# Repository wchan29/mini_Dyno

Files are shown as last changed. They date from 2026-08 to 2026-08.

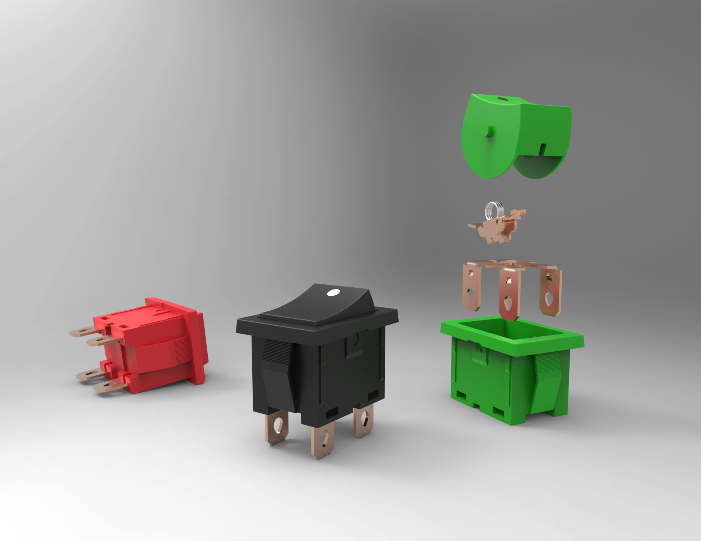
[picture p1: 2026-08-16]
Dyno Enclosure REV_B/220 - Electronics/220 - Electronics Encapsulation/OnOff Switch/on-off-switch-4.snapshot.2/Renderings/On off switch.1.jpg

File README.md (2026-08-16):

# Mini Dyno

Mechanical design files for a compact 10 N·m dynamometer built for the [WEMPEC](https://wempec.wisc.edu/) research lab at UW-Madison.

## Overview

A dynamometer measures the rotational speed and torque output of a motor to determine instantaneous power and efficiency. This project is a bench-scale dynamometer for characterizing small electric machines (up to IEC100 frame size), designed to:

- Fit on a standard lab bench
- House a pre-selected Rockwell Kinetix MP servo as the load motor
- Enclose the test setup for operator protection
- Allow quick installation/removal of test motors with minimal realignment
- Support HMI control from the enclosure door

More background and photos: https://wchan29.github.io/portfolio/wempec_mini_dyne/

## Design

**Mechanical**
- ThorLabs MB3090/M aluminum optical breadboard as the baseplate
- MISUMI L-shaped welded mounts for servo motor attachment
- OptoSigma optical rails and carriages for interchangeable test-motor mounting
- 8020 T-slot aluminum framing for the enclosure
- 1/4" polycarbonate protective panels

**Electrical**
- Servo drive: Allen-Bradley Kinetix 300 (2097-V33PR6, 3 kW)
- Load motor: Rockwell Kinetix MPL-A4540F-MJ74AA (2.6 kW, 3000 RPM)
- HMI: 7" Rockwell PanelView 800 touchscreen mounted on the enclosure door
- Controller: Micro820 PLC over Ethernet
- Supporting hardware: 24V DC power supply, Ethernet hub, brake relay, torque transducer module

**Specs**
- Max torque: 10 N·m
- Max speed: 3000 RPM

The servo and torque transducer are mounted as a swappable unit on the optical rail carriage, so either can be serviced or replaced independently of the rest of the setup.

## Repository contents

All design files live under [`Dyno Enclosure REV_B/`](Dyno%20Enclosure%20REV_B/), a SolidWorks project:

| Folder / File | Contents |
| --- | --- |
| `220 - Dyno Enclosure - 8020/` | T-slot frame, door, and hinge assemblies |
| `220 - Dyno Enclosure - Optical Table/` | Optical breadboard baseplate |
| `220 - Dyno Enclosure - OptoSigma/` | Optical rail and carriage components |
| `220 - Dyno Enclosure - Polycarbonate/` | Enclosure panels |
| `220 - Optical Rail and Carriage/` | Motor mounting carriage hardware |
| `220 - Bracket & Misc/` | Brackets, alignment jig, torque transducer base, couplings |
| `220 - Cable Routing/` | Cable management components |
| `220 - Electronics/` | Electrical/control hardware models |
| `Pictures/` | Reference images |
| `220 - Dyno Enclosure - BOM.SLDDRW` / `..._BOM_PDF.pdf` | Bill of materials |
| `_220 - Dyno Enclosure - Enclosure Full Assembly.SLDASM` | Top-level enclosure assembly |
| `220 - Dyno Setup Assembly.SLDASM` | Top-level full dyno assembly |

Files are native SolidWorks (`.SLDPRT`/`.SLDASM`/`.SLDDRW`), with some parts also provided as `.igs`/`.DXF`/`.pdf` for interchange. Requires SolidWorks (or a compatible viewer) to open.

## License

This work is licensed under [CC BY 4.0](LICENSE).

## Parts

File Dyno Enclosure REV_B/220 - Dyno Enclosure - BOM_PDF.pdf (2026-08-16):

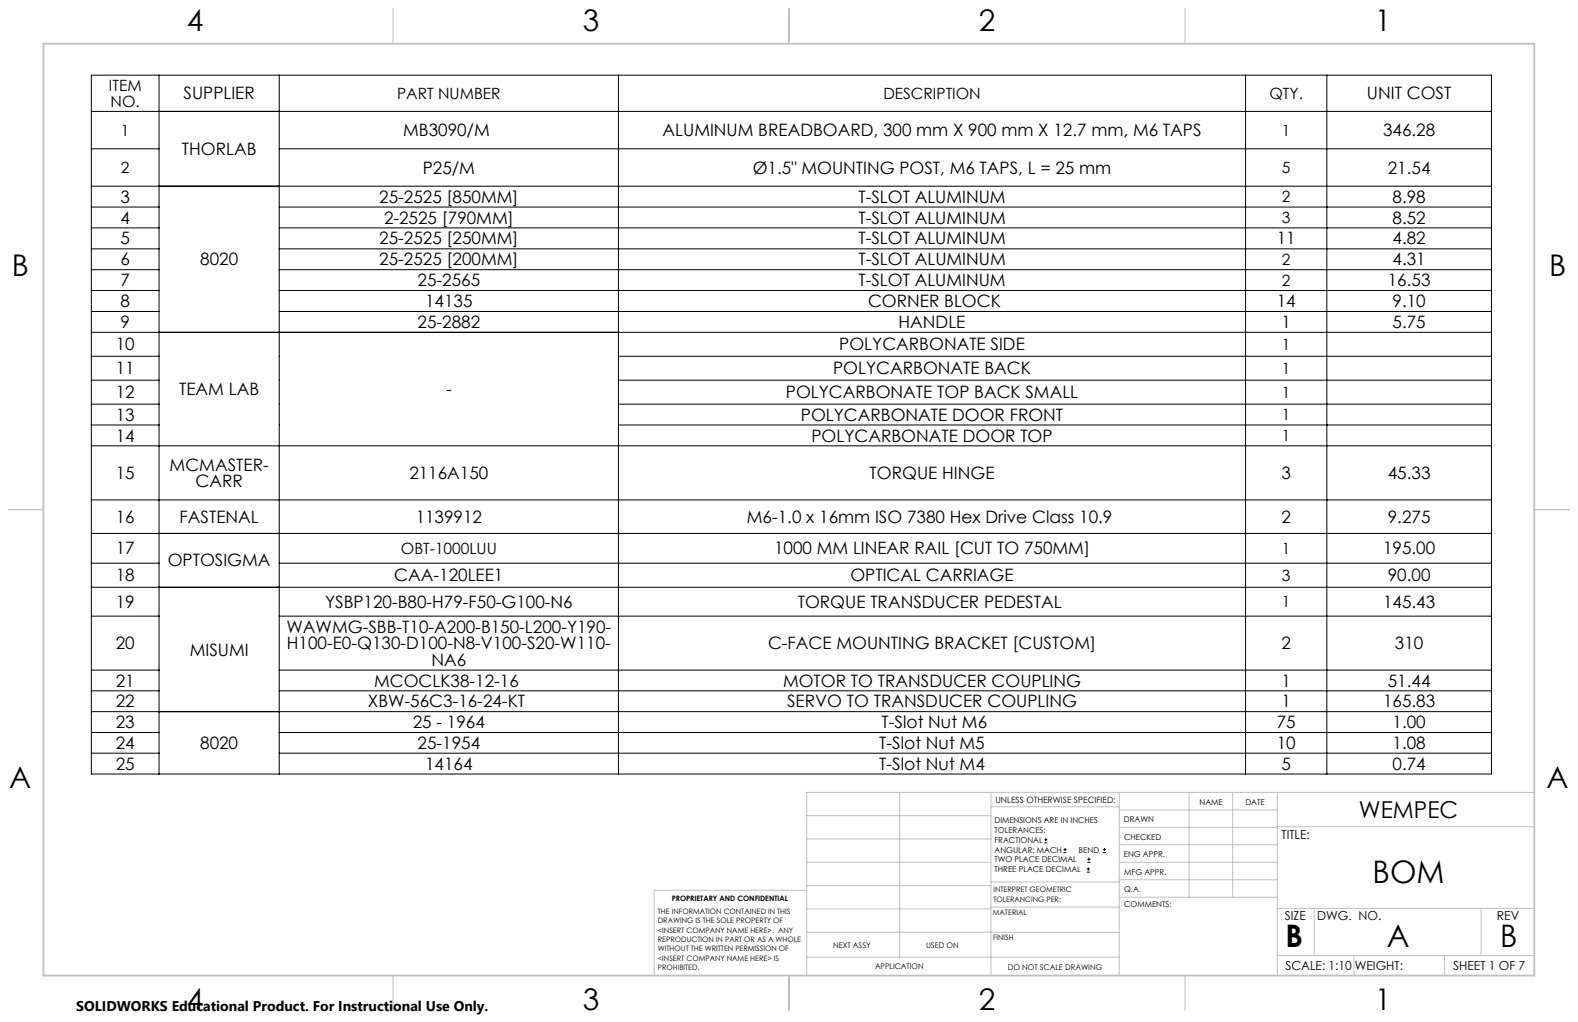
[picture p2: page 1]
SUPPLIER; PART NUMBER; DESCRIPTION; QTY.; UNIT COST; ALUMINUM BREADBOARD, 300 mm X 900 mm X 12.7 mm, M6 TAPS; Ø1.5" MOUNTING POST, M6 TAPS, L = 25 mm; T-SLOT ALUMINUM; CORNER BLOCK; TEAM LAB; POLYCARBONATE SIDE; POLYCARBONATE BACK; POLYCARBONATE TOP BACK SMALL; POLYCARBONATE DOOR FRONT; POLYCARBONATE DOOR TOP; CARR; TORQUE HINGE; FASTENAL; M6-1.0 x 16mm ISO 7380 Hex Drive Class 10.9; OPTOSIGMA; OBT-1000LUU; 1000 MM LINEAR RAIL [CUT TO 750MM]; CAA-120LEE1; OPTICAL CARRIAGE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

UNLESS OTHERWISE SPECIFIED: | | DATE | WEMPEC NAME
DIMENSIONS ARE IN INCHES TOLERANCES: FRACTIONAL ANGULAR: MACH BEND TWO PLACE DECIMAL THREE PLACE DECIMAL | DRAWN

CHECKED | | TITLE: BOM

ENG APPR.
MFG APPR.

INTERPRET GEOMETRIC TOLERANCING PER: | Q.A.
MATERIAL | | SIZE B | DWG. NO. A | REV B

PROPRIETARY AND CONFIDENTIAL
THE INFORMATION CONTAINED IN THIS
DRAWING IS THE SOLE PROPERTY OF
<INSERT COMPANY NAME HERE>. ANY
REPRODUCTION IN PART OR AS A WHOLE
WITHOUT THE WRITTEN PERMISSION OF
<INSERT COMPANY NAME HERE> IS
PROHIBITED.

NEXT ASSY | USED ON | FINISH

APPLICATION | DO NOT SCALE DRAWING | | SCALE: 1:10 WEIGHT: | | SHEET 1 OF 7

SOLIDWORKS Educational Product. For Instructional Use Only.

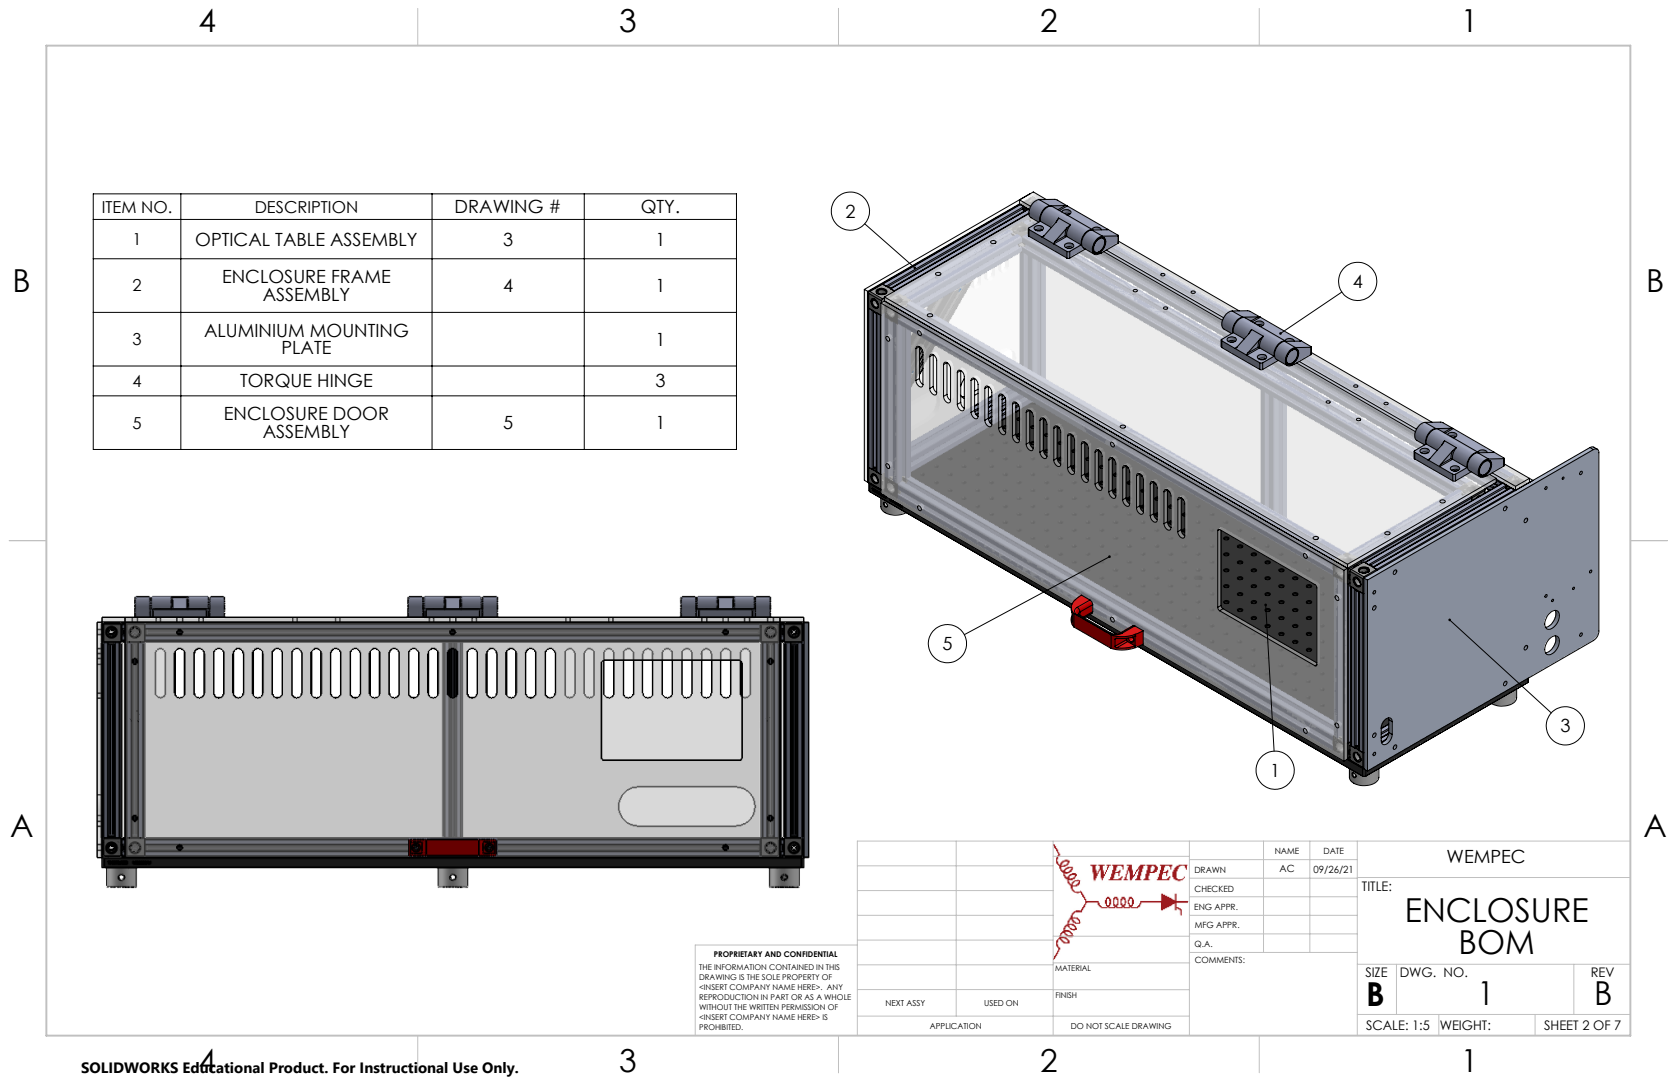
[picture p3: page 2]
SCALE: 1:5; WEIGHT:; DWG. NO.; REV

ITEM NO. | DESCRIPTION | DRAWING # | QTY.
1 | OPTICAL TABLE ASSEMBLY | 3 | 1
2 | ENCLOSURE FRAME ASSEMBLY | 4 | 1

3 | ALUMINIUM MOUNTING PLATE | | 1

4 | TORQUE HINGE | | 3
5 | ENCLOSURE DOOR ASSEMBLY | 5 | 1

NAME | DATE | WEMPEC
CHECKED | | | TITLE: ENCLOSURE BOM

DRAWN | AC | 09/26/21

ENG APPR.
MFG APPR.
Q.A.

PROPRIETARY AND CONFIDENTIAL
THE INFORMATION CONTAINED IN THIS
DRAWING IS THE SOLE PROPERTY OF
<INSERT COMPANY NAME HERE>. ANY

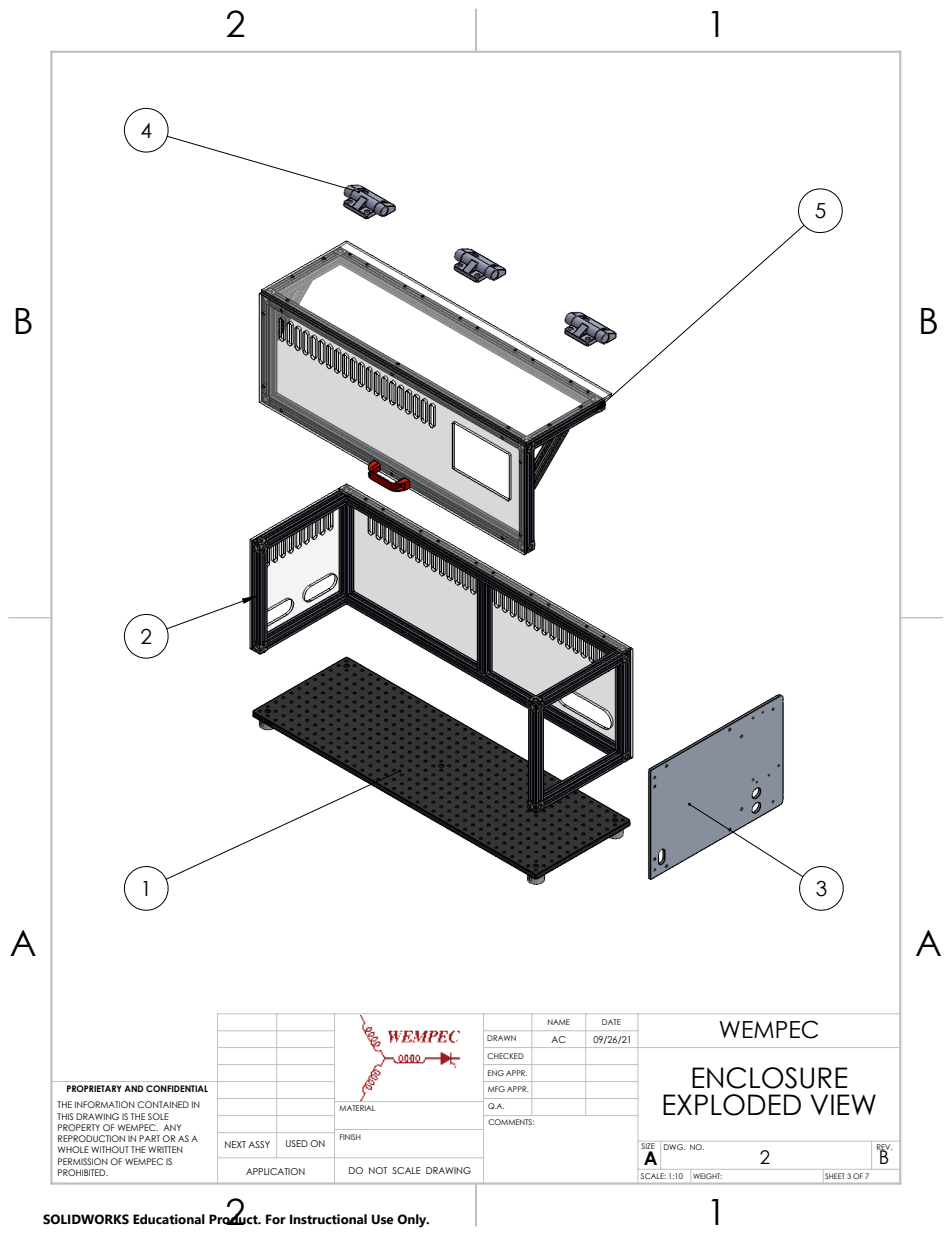
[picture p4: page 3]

AC NAME | 09/26/21 DATE | WEMPEC EXPLODED VIEW PROPRIETARY AND CONFIDENTIAL

DRAWN
CHECKED | | | ENCLOSURE
ENG APPR.

THE INFORMATION CONTAINED IN THIS DRAWING IS THE SOLE PROPERTY OF WEMPEC. ANY REPRODUCTION IN PART OR AS A WHOLE WITHOUT THE WRITTEN PERMISSION OF WEMPEC IS | | MFG APPR.

MATERIAL | Q.A.

SIZE A | DWG. NO. 2 | REV. B

APPLICATION | DO NOT SCALE DRAWING

SCALE: 1:10 | WEIGHT:

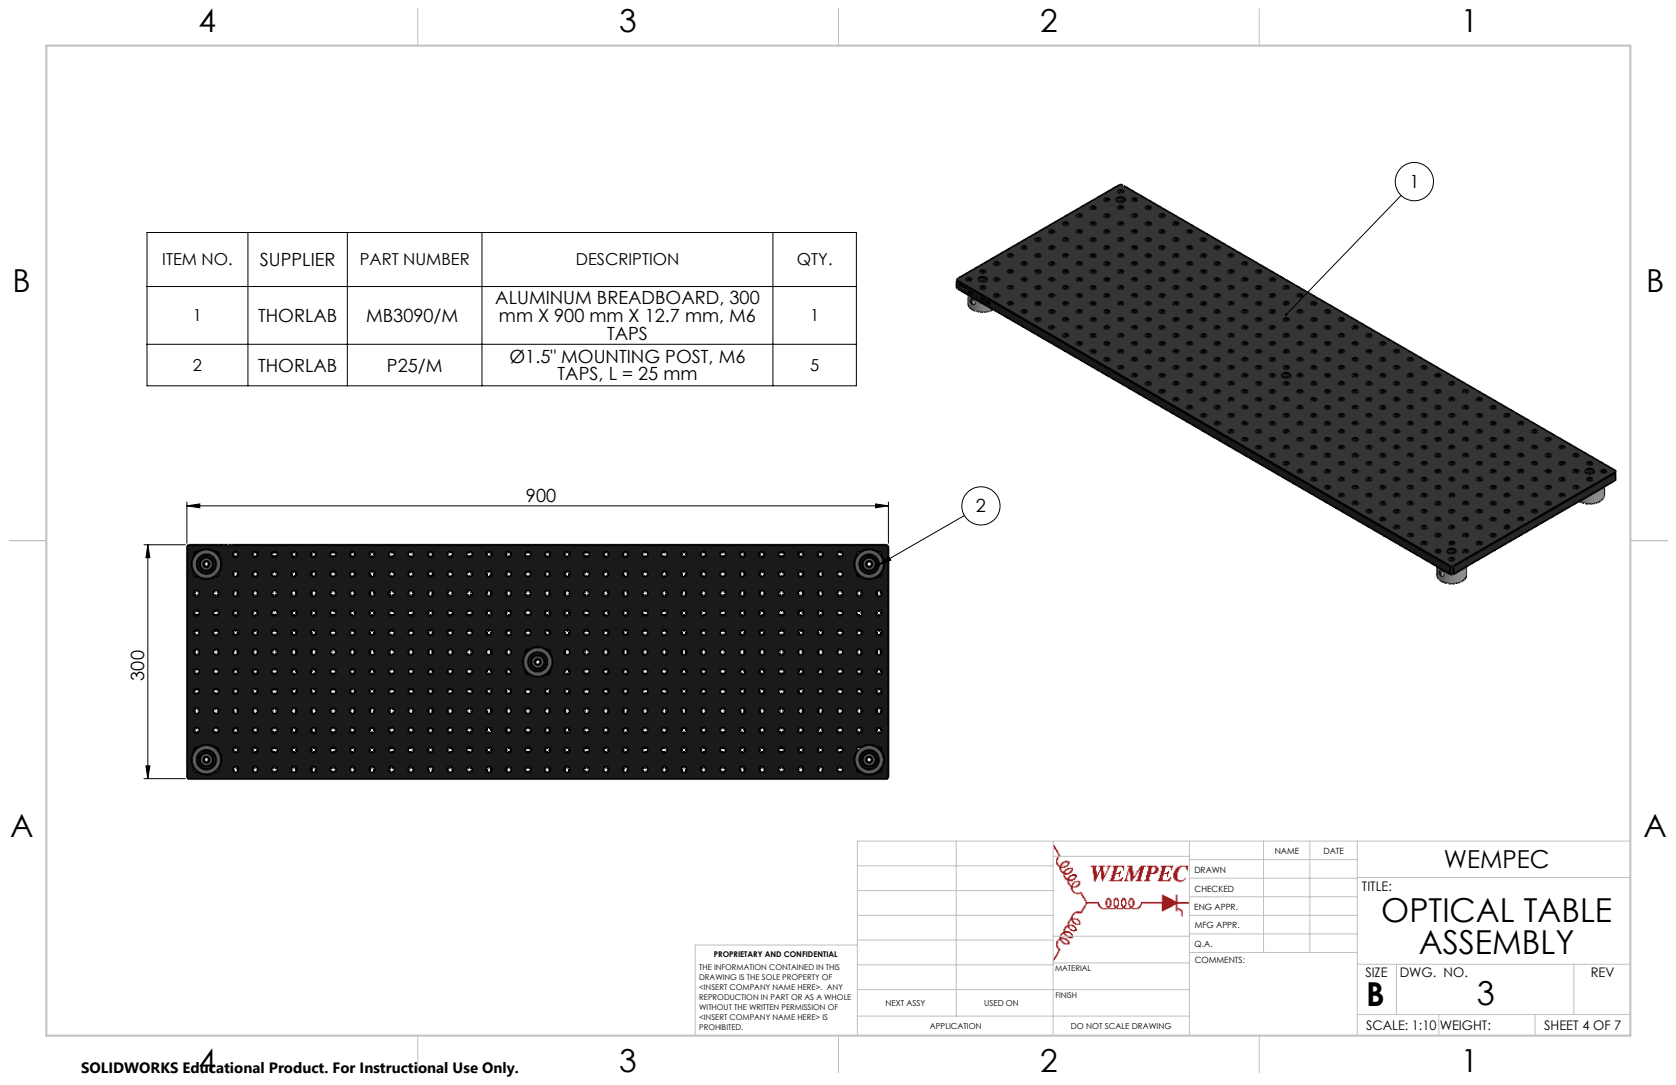
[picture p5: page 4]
SCALE: 1:10 WEIGHT:; SHEET 4 OF 7; DWG. NO.; REV

ITEM NO. | SUPPLIER | PART NUMBER | DESCRIPTION | QTY.
1 | THORLAB | MB3090/M | ALUMINUM BREADBOARD, 300 mm X 900 mm X 12.7 mm, M6 TAPS | 1

2 | THORLAB | P25/M | Ø1.5" MOUNTING POST, M6 TAPS, L = 25 mm | 5

DATE | WEMPEC NAME
CHECKED | TITLE: OPTICAL TABLE ASSEMBLY

DRAWN

ENG APPR.
MFG APPR.
Q.A.

PROPRIETARY AND CONFIDENTIAL
THE INFORMATION CONTAINED IN THIS
DRAWING IS THE SOLE PROPERTY OF
<INSERT COMPANY NAME HERE>. ANY

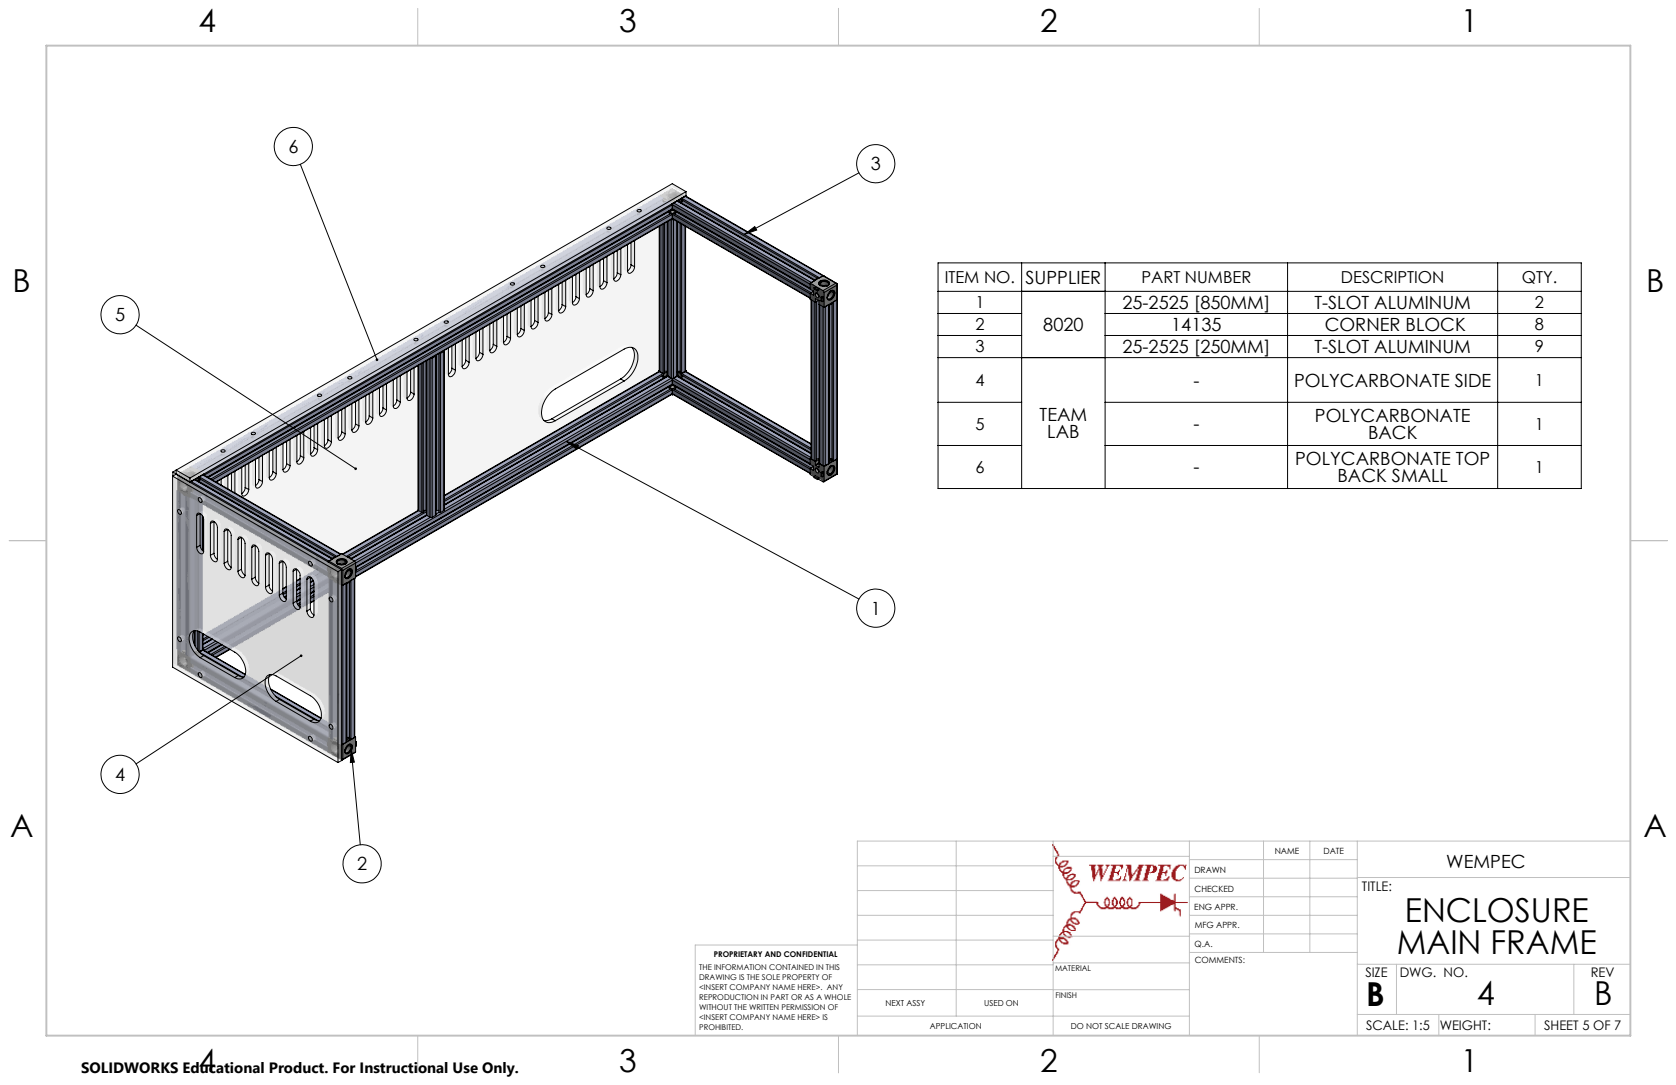
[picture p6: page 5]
SCALE: 1:5; WEIGHT:; SHEET 5 OF 7; DWG. NO.; REV

ITEM NO. | SUPPLIER | PART NUMBER | DESCRIPTION | QTY.
1 | 8020 | 25-2525 [850MM] | T-SLOT ALUMINUM | 2
2 | | 14135 | CORNER BLOCK | 8
3 | | 25-2525 [250MM] | T-SLOT ALUMINUM | 9
4 | TEAM LAB | - | POLYCARBONATE SIDE | 1
5 | | - | POLYCARBONATE BACK | 1
6 | | - | POLYCARBONATE TOP BACK SMALL | 1

NAME | DATE | WEMPEC
CHECKED | | | TITLE: ENCLOSURE MAIN FRAME

DRAWN

ENG APPR.
MFG APPR.
Q.A.

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

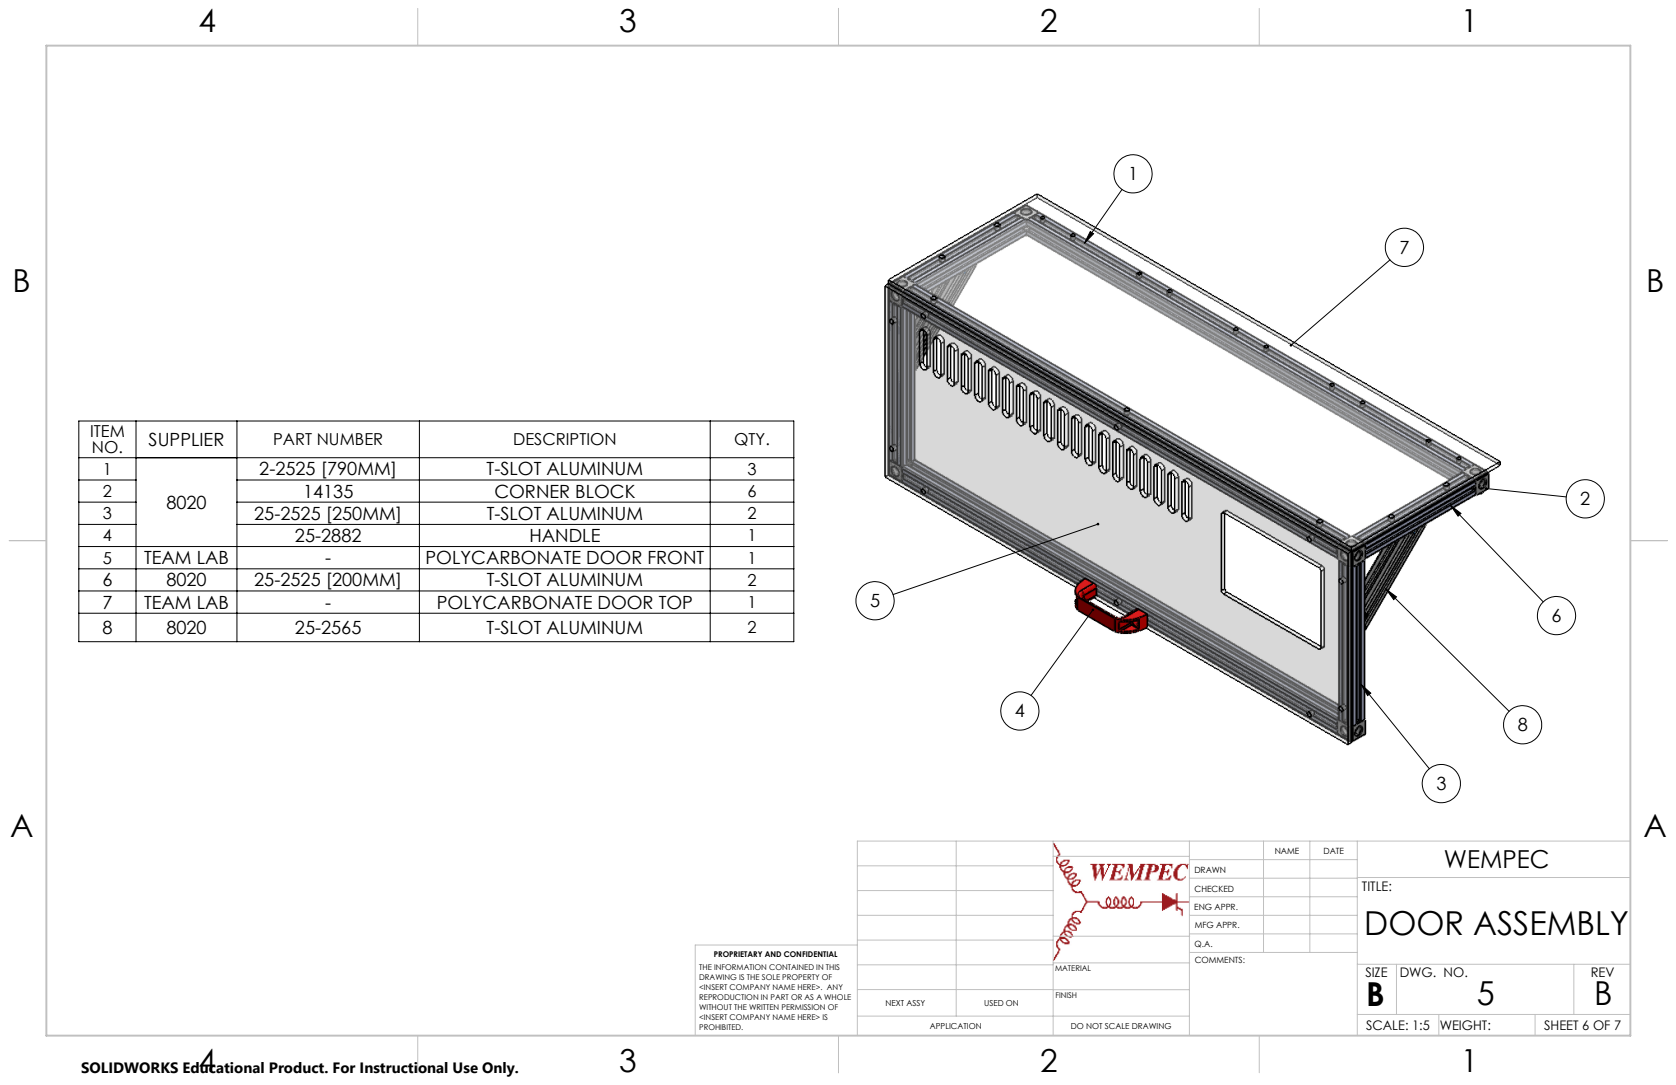
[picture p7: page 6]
SCALE: 1:5; WEIGHT:; SHEET 6 OF 7; DWG. NO.; REV

ITEM NO. | SUPPLIER | PART NUMBER | DESCRIPTION | QTY.
1 | 8020 | 2-2525 [790MM] | T-SLOT ALUMINUM | 3
2 | | 14135 | CORNER BLOCK | 6
3 | | 25-2525 [250MM] | T-SLOT ALUMINUM | 2
4 | | 25-2882 | HANDLE | 1
5 | TEAM LAB | - | POLYCARBONATE DOOR FRONT | 1
6 | 8020 | 25-2525 [200MM] | T-SLOT ALUMINUM | 2
7 | TEAM LAB | - | POLYCARBONATE DOOR TOP | 1
8 | 8020 | 25-2565 | T-SLOT ALUMINUM | 2

DATE | WEMPEC NAME
CHECKED | TITLE: DOOR ASSEMBLY

DRAWN

ENG APPR.
MFG APPR.
Q.A.

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

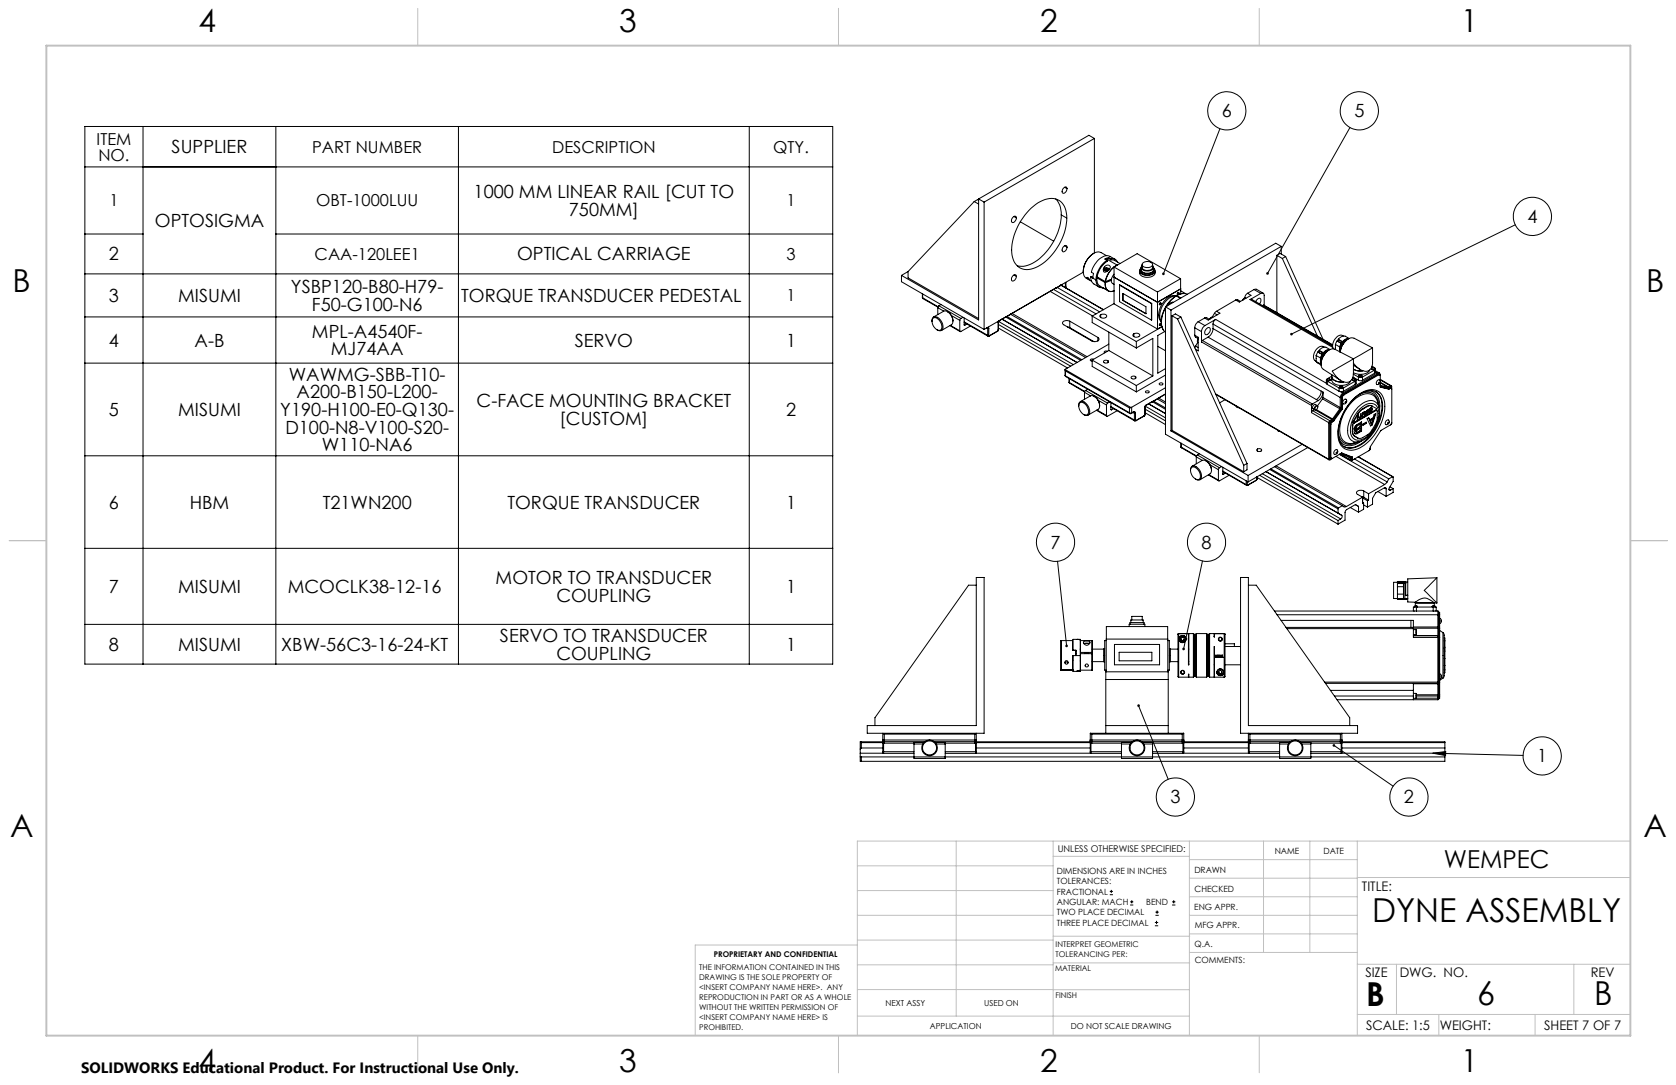
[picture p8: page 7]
SCALE: 1:5; WEIGHT:; DWG. NO.; REV

ITEM NO. | SUPPLIER | PART NUMBER | DESCRIPTION | QTY.

1 | OPTOSIGMA | OBT-1000LUU | 1000 MM LINEAR RAIL [CUT TO 750MM] | 1

2 | | CAA-120LEE1 | OPTICAL CARRIAGE | 3
3 | MISUMI | YSBP120-B80-H79-F50-G100-N6 | TORQUE TRANSDUCER PEDESTAL | 1
4 | A-B | MPL-A4540F-MJ74AA | SERVO | 1
5 | MISUMI | WAWMG-SBB-T10-A200-B150-L200-Y190-H100-E0-Q130-D100-N8-V100-S20-W110-NA6 | C-FACE MOUNTING BRACKET [CUSTOM] | 2

6 | HBM | T21WN200 | TORQUE TRANSDUCER | 1

7 | MISUMI | MCOCLK38-12-16 | MOTOR TO TRANSDUCER COUPLING | 1

8 | MISUMI | XBW-56C3-16-24-KT | SERVO TO TRANSDUCER COUPLING | 1

UNLESS OTHERWISE SPECIFIED: | | DATE | WEMPEC NAME
DIMENSIONS ARE IN INCHES TOLERANCES: FRACTIONAL ANGULAR: MACH BEND TWO PLACE DECIMAL THREE PLACE DECIMAL | DRAWN

CHECKED | | TITLE: DYNE ASSEMBLY

ENG APPR.
MFG APPR.

INTERPRET GEOMETRIC TOLERANCING PER: | Q.A.

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

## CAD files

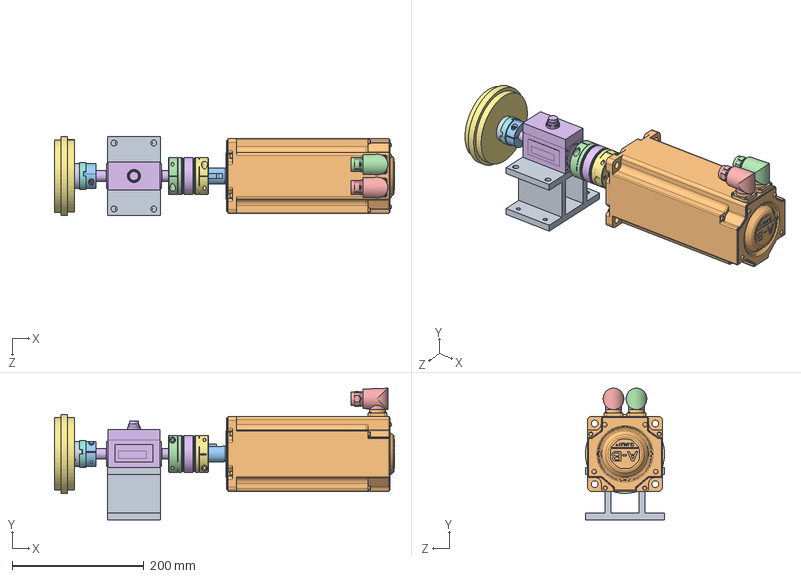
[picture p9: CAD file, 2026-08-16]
Dyno Enclosure REV_B/220 - Dyno Setup Assembly.SLDASM
515.2 x 199.6 x 120.0 mm
220 - Torque Transducer Base - YSBP120_B80_H79_F50_G100_N6
Rockwell Automation-MPL-x4540x-xJ74AA_MPL-45xx-Body
Rockwell Automation-MPL-x4540x-xJ74AA_MPL-45xx-Shaft
Rockwell Automation-MPL-x4540x-xJ74AA_MPL-3xx-Power Connector
Rockwell Automation-MPL-x4540x-xJ74AA_MPL-3xx-Encoder Connector
T21WN_20_0_SW
_MCOC_spacer38_2
_MCOCLK38_12_c_4
_M5_16_bo2_6 x 2
_MCOC38_16_c_8
_XBW-56C3 - 16-24 - Hub 1.stp
_XBW-56C3 - Disk.stp x 2
_XBW-56C3 - Spacer.stp
_XBW-56C3 - 16-24 - Hub 2.stp

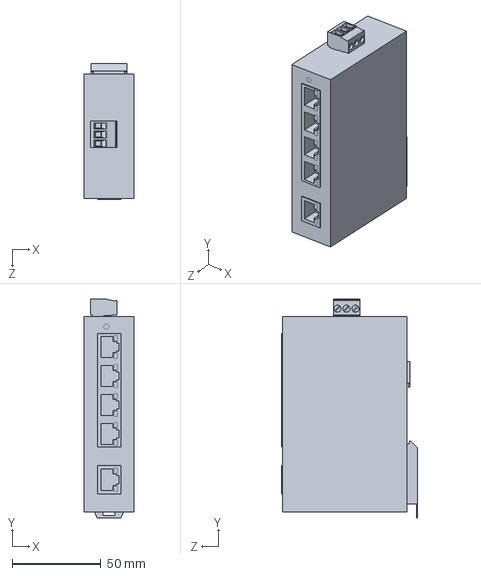
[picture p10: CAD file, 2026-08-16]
Dyno Enclosure REV_B/220 - Electronics/220 - PXC - FL-SWITCH-SFNB-5TX_3D/220 - PXC - FL-SWITCH-SFNB-5TX_3D.SLDASM
28.0 x 123.2 x 76.7 mm

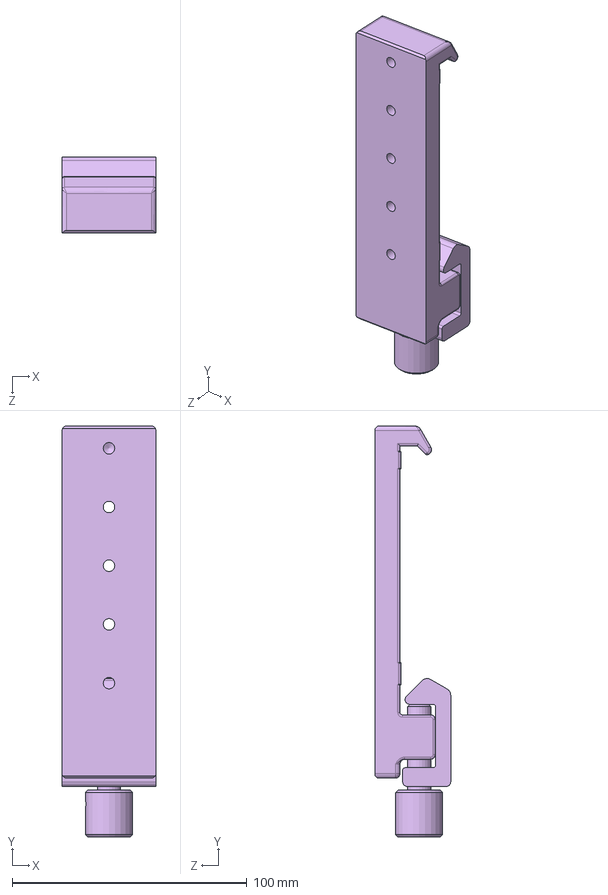
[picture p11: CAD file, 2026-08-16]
Dyno Enclosure REV_B/220 - Optical Rail and Carriage/CAA-40LEE.SLDASM
40.0 x 175.1 x 32.2 mm
CAA-40LEE1
CAA-40LEE2
CAA-40LEE3
CAA-40LEE4
CAA-40LEE5
CAA-40LEE6

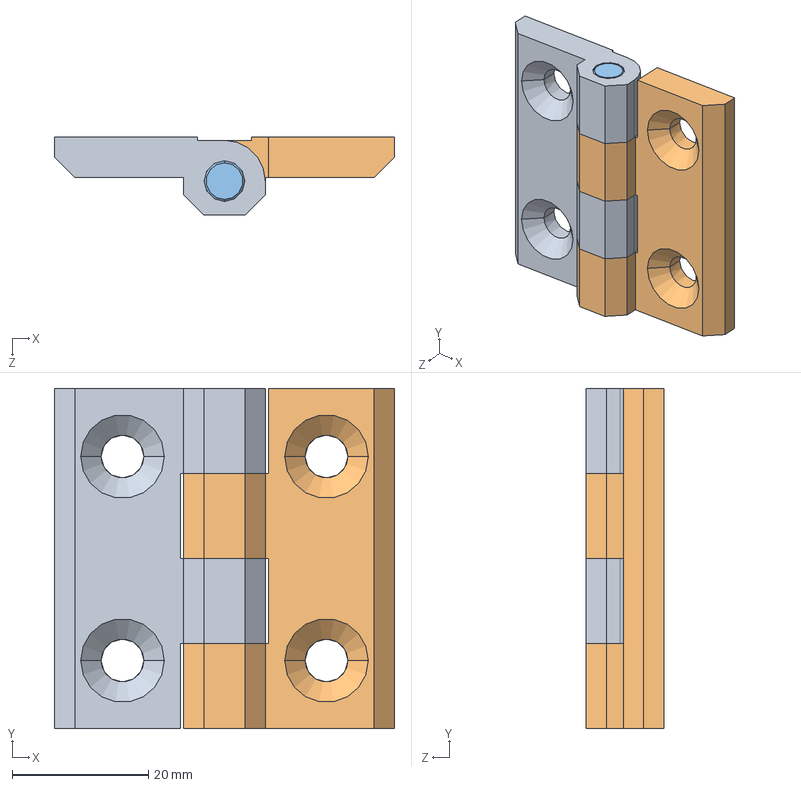
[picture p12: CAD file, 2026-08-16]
Dyno Enclosure REV_B/220 - Dyno Enclosure - 8020/220 - Hinge/220 - Dyno Enclosure - 8020 - Hinge - 12256.sldasm
50.0 x 50.0 x 11.5 mm
_12256_a_2
_12256_b_4
_12256_pin_6

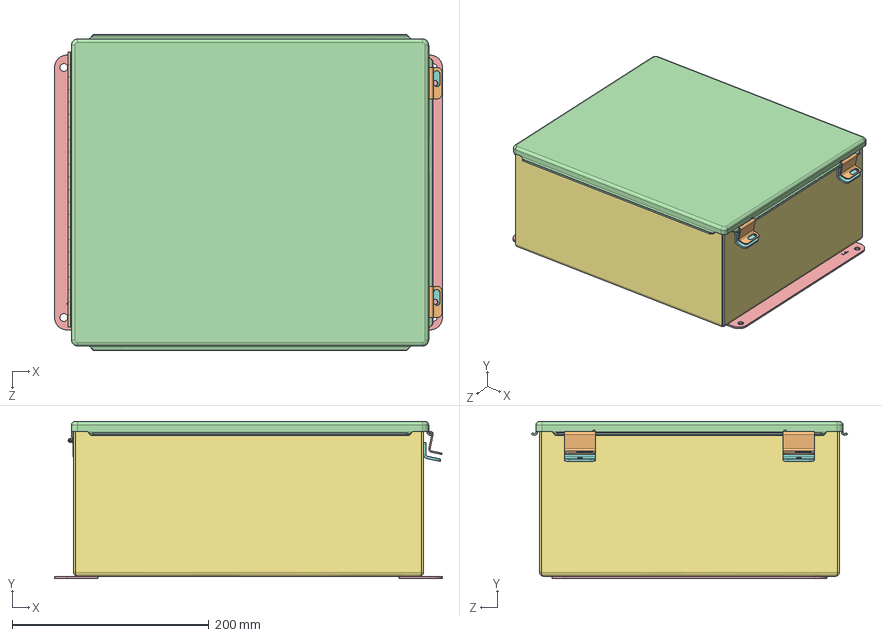
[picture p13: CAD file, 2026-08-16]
Dyno Enclosure REV_B/220 - Electronics/220 - Electronics Encapsulation/220 - Dyno Enclosure - Electronics Box.SLDASM
394.2 x 159.8 x 321.1 mm
89053215.stp
89053200.stp x 2
99404181.stp
58346025.stp
54208005_54208005.stp x 2
54106001.stp x 4
54321010.stp
54102001.stp x 2
54206007_PER MODEL.stp
54101001.stp x 2

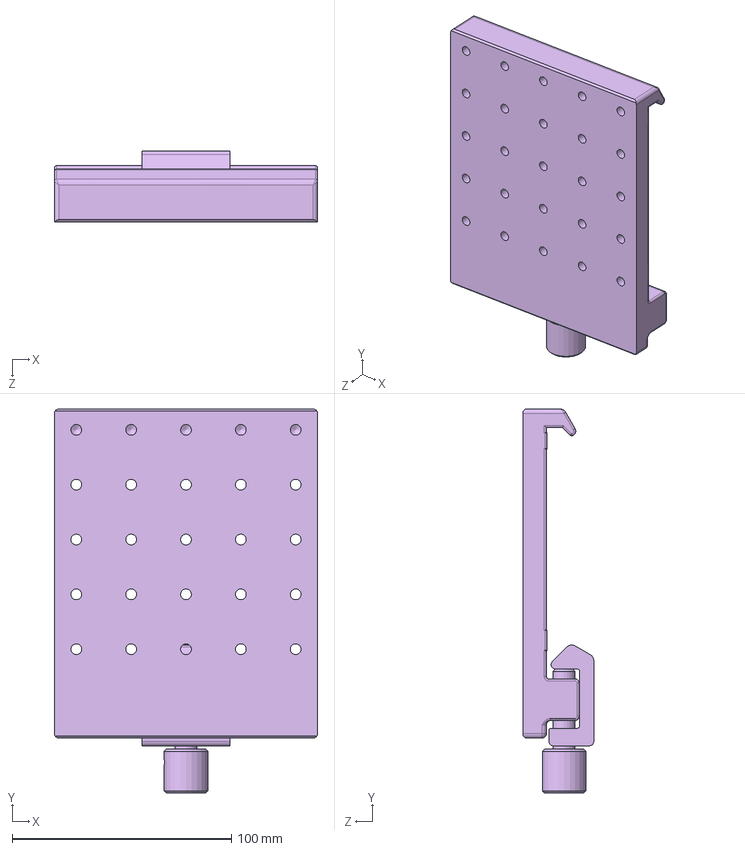
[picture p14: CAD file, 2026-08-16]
Dyno Enclosure REV_B/220 - Optical Rail and Carriage/CAA-120LEE.SLDASM
120.0 x 175.1 x 32.2 mm
CAA-120LEE1
CAA-120LEE2
CAA-120LEE3
CAA-120LEE4
CAA-120LEE5
CAA-120LEE6

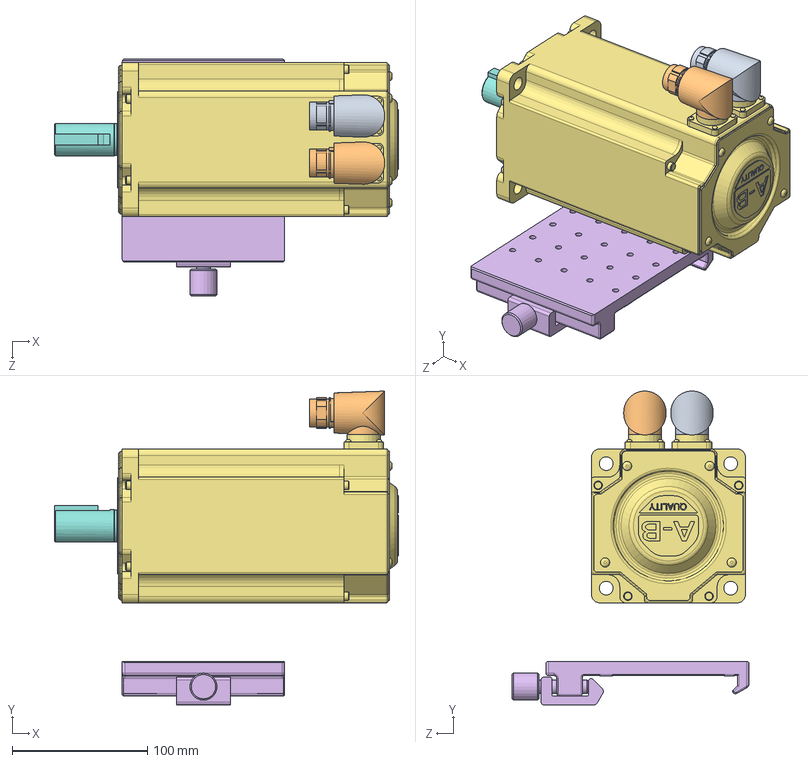
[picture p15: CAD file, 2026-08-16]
Dyno Enclosure REV_B/220 - Motor Carriage.SLDASM
254.0 x 231.8 x 175.1 mm
CAA-120LEE1
CAA-120LEE2
CAA-120LEE3
CAA-120LEE4
CAA-120LEE5
CAA-120LEE6
Rockwell Automation-MPL-x4540x-xJ74AA_MPL-45xx-Body
Rockwell Automation-MPL-x4540x-xJ74AA_MPL-45xx-Shaft
Rockwell Automation-MPL-x4540x-xJ74AA_MPL-3xx-Power Connector
Rockwell Automation-MPL-x4540x-xJ74AA_MPL-3xx-Encoder Connector

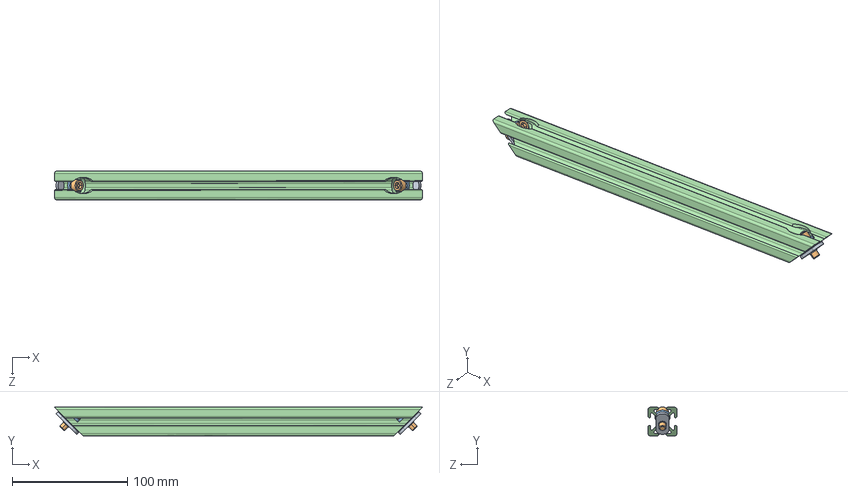
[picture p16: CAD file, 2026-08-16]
Dyno Enclosure REV_B/220 - Dyno Enclosure - 8020/8020_252570/SOLIDWORKS/25_2570.sldasm
320.0 x 25.2 x 25.0 mm

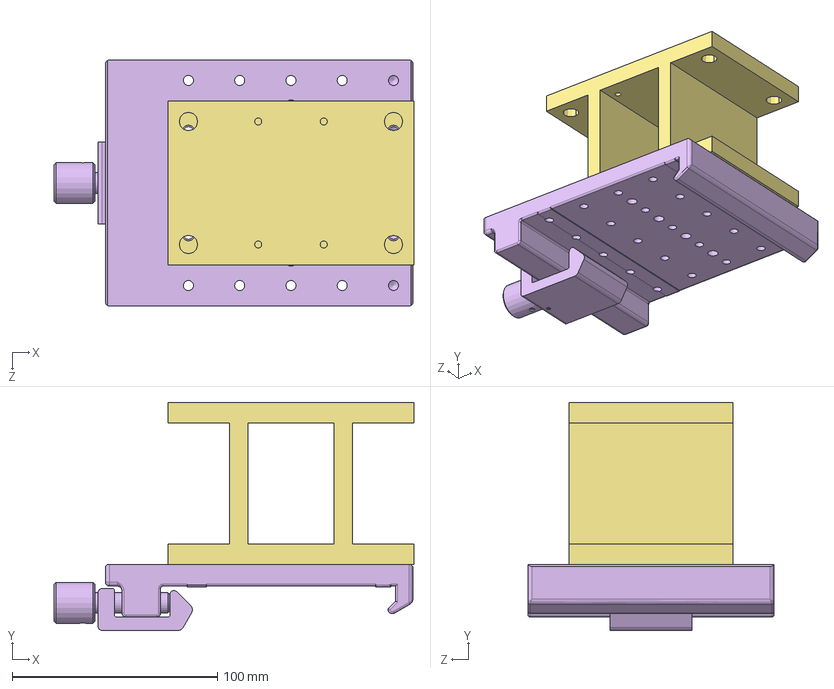
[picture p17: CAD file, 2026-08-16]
Dyno Enclosure REV_B/220 - Torque Transducer Carraige.SLDASM
175.5 x 111.2 x 120.0 mm
CAA-120LEE1
CAA-120LEE2
CAA-120LEE3
CAA-120LEE4
CAA-120LEE5
CAA-120LEE6
220 - Torque Transducer Base - YSBP120_B80_H79_F50_G100_N6

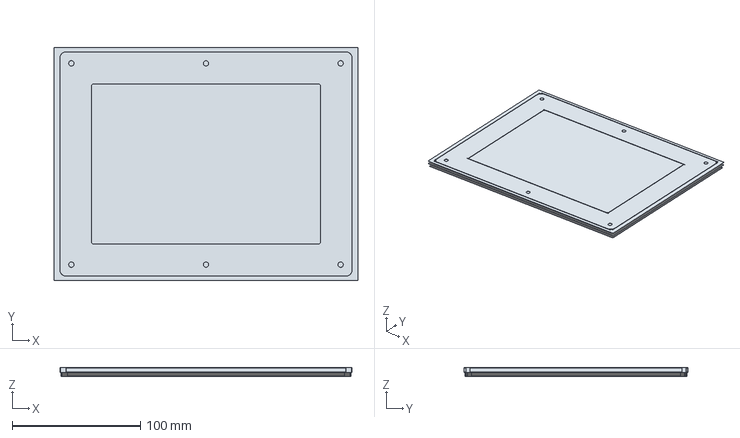
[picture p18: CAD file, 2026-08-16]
Dyno Enclosure REV_B/220 - Dyno Enclosure - Polycarbonate/2711R_APK7_Assy_3D.igs
237.1 x 182.0 x 7.04 mm

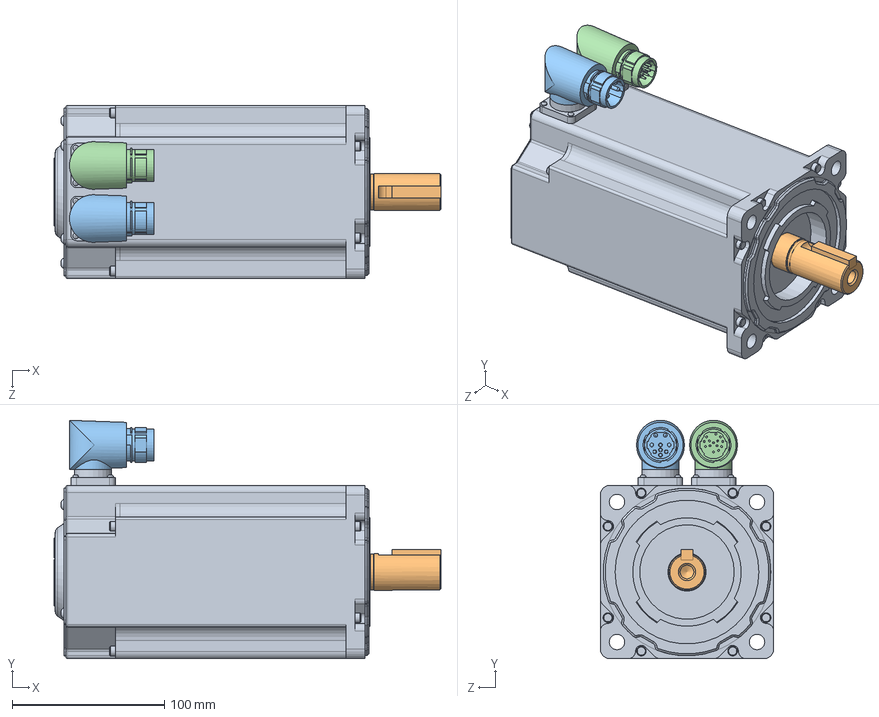
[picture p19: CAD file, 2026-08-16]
Dyno Enclosure REV_B/220 - Electronics/220 - Rockwell Automation-MPL-X4540X-XJ74AA Motor/Rockwell Automation-MPL-x4540x-xJ74AA.SLDASM
254.0 x 156.5 x 113.8 mm
Rockwell Automation-MPL-x4540x-xJ74AA_MPL-45xx-Body
Rockwell Automation-MPL-x4540x-xJ74AA_MPL-45xx-Shaft
Rockwell Automation-MPL-x4540x-xJ74AA_MPL-3xx-Power Connector
Rockwell Automation-MPL-x4540x-xJ74AA_MPL-3xx-Encoder Connector

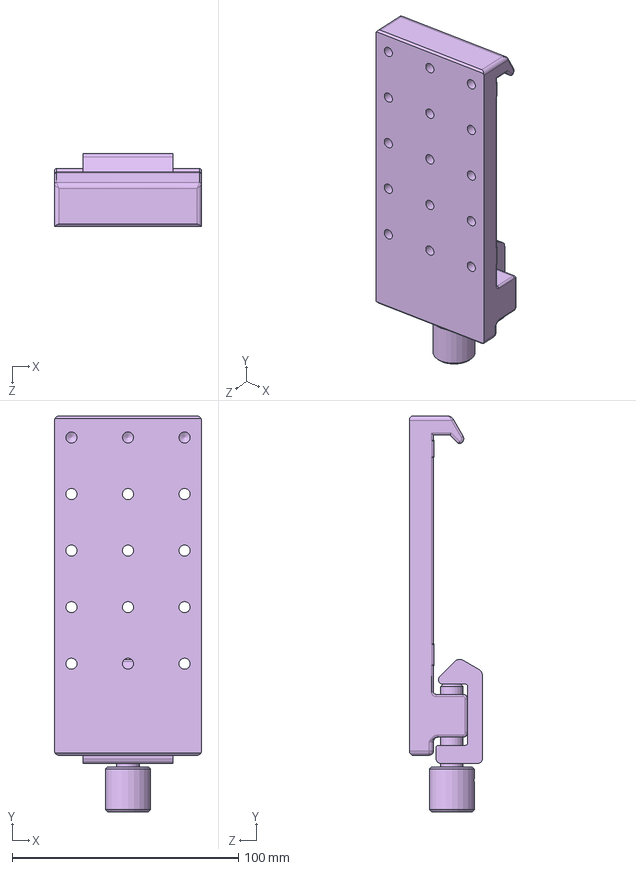
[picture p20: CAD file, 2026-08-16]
Dyno Enclosure REV_B/220 - Dyno Enclosure - OptoSigma/220 - Optical Carriage/CAA-65LEE.SLDASM
65.0 x 175.1 x 32.2 mm
CAA-65LEE1
CAA-65LEE2
CAA-65LEE3
CAA-65LEE4
CAA-65LEE5
CAA-65LEE6

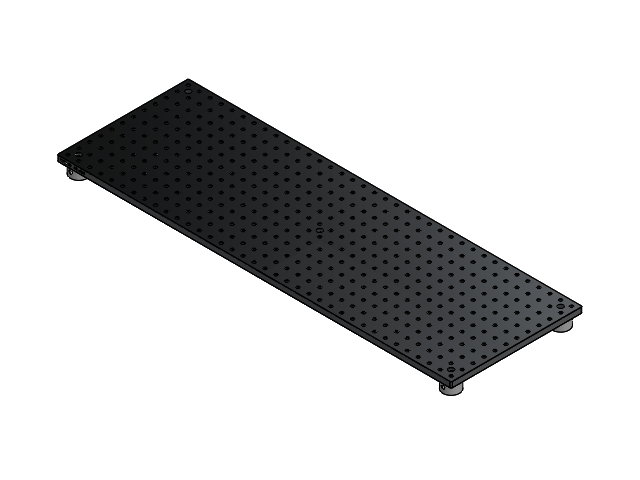
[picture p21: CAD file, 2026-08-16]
Dyno Enclosure REV_B/220 - Dyno Enclosure - Optical Table/220 - Optical Table - Optical Table Assembly.SLDASM
220 - Optical Table - MB3090_M-Solidworks
220 - Optical Table - P25_M-Solidworks x 5

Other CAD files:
Dyno Enclosure REV_B/220 - Bracket & Misc/220 - Dyno Enclosure - Couplings/12- 16 mm/MCOCLK38_12_16.sldasm
Dyno Enclosure REV_B/220 - Dyno Enclosure - OptoSigma/220 - Optical Carriage/CAA-120LEE.SLDASM
Dyno Enclosure REV_B/220 - Electronics/220 - Rockwell Automation-MPL-X4540X-XJ74AA Motor/Cable_1-Rockwell Automation-MPL-x4540x-xJ74AA.sldasm
Dyno Enclosure REV_B/220 - Dyno Enclosure - 8020/8020_252565/SOLIDWORKS/25_2565.sldasm
Dyno Enclosure REV_B/220 - Motor Carriage - Left.SLDASM
Dyno Enclosure REV_B/220 - Bracket & Misc/220 - Alignment Jig.SLDDRW
Dyno Enclosure REV_B/220 - Bracket & Misc/220 - Alignment Jig.SLDPRT
Dyno Enclosure REV_B/220 - Bracket & Misc/220 - BRACKET- Drawing.SLDDRW
Dyno Enclosure REV_B/220 - Bracket & Misc/220 - Carriage - Drawing CAA-120LEE6.SLDDRW
Dyno Enclosure REV_B/220 - Bracket & Misc/220 - Dyno Enclosure - Aluminium Mounting Plate.DXF
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

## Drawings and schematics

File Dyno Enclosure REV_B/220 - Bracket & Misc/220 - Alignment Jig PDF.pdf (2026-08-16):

B B

2

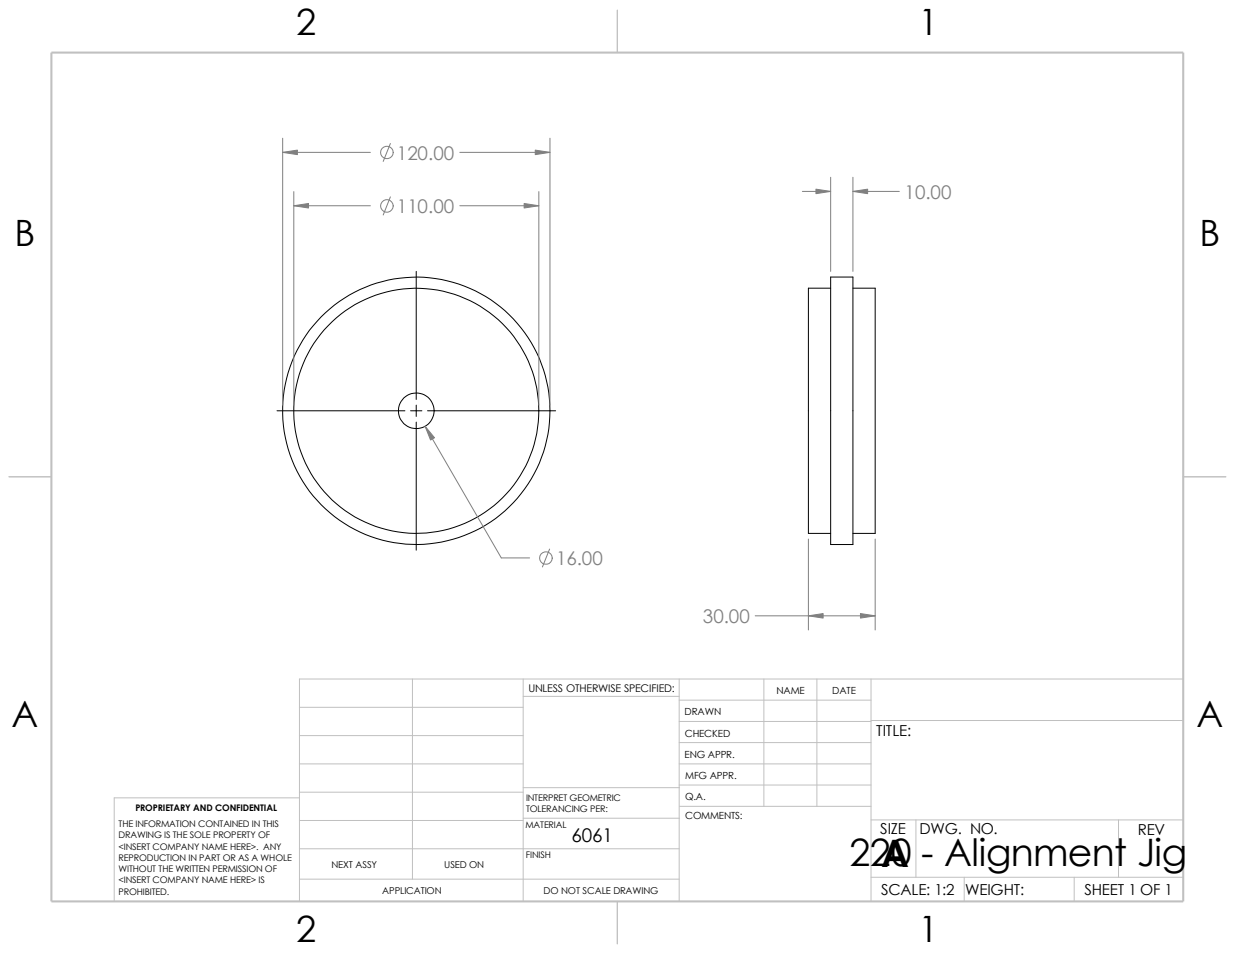
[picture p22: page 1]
220 - Alignment Jig; COMMENTS:

UNLESS OTHERWISE SPECIFIED: | | NAME | DATE

DRAWN
CHECKED | | | TITLE:

ENG APPR.
MFG APPR.

INTERPRET GEOMETRIC TOLERANCING PER: | Q.A.
MATERIAL 6061 | | SIZE A | DWG. NO. | REV

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

NEXT ASSY | USED ON | FINISH

APPLICATION | DO NOT SCALE DRAWING | | SCALE: 1:2 | WEIGHT: | SHEET 1 OF 1
